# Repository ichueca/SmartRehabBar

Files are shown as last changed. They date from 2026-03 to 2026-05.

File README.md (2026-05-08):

# SmartRehabBar

**SmartRehabBar** es un proyecto centrado en el **desarrollo de un sistema inteligente que se integra en barras de rehabilitación**, permitiendo medir de forma objetiva la fuerza de apoyo ejercida por pacientes durante ejercicios de recuperación funcional.

El sistema utiliza **células de carga** para registrar la carga aplicada, enviando los datos en tiempo real a una plataforma web para su visualización. Esto permite a los profesionales sanitarios realizar un seguimiento cuantitativo de la evolución del paciente.

Además, el proyecto está diseñado con un enfoque **educativo y modular**, facilitando su uso en Formación Profesional y permitiendo futuras ampliaciones como análisis avanzado e integración de inteligencia artificial.

---

## 🎯 Objetivos del proyecto

* Medir de forma objetiva la **fuerza de apoyo** durante ejercicios de rehabilitación.
* Registrar el **tiempo de carga** y detectar descompensaciones.
* Facilitar datos cuantitativos al fisioterapeuta.
* Desarrollar un sistema **replicable, modular y de bajo coste**.
* Servir como base para futuras ampliaciones (doble apoyo, IA, análisis avanzado).

---

## 🧩 Arquitectura general del sistema

El sistema electrónico se compone de los siguientes bloques:

1. Sensórica de fuerza mediante células de carga.
2. Amplificación y conversión ADC con HX711.
3. Microcontrolador ESP32 para procesado y comunicaciones.
4. Sistema de alimentación autónomo con batería Li-Ion.
5. Comunicación WiFi con servidor remoto para visualización de datos.

---

## 🧪 Material electrónico utilizado

### Sensores

* **Células de carga resistivas** (galgas extensométricas).
* Configuración en puente de Wheatstone para mayor estabilidad.

### Conversión y amplificación

* **HX711**

  * ADC de 24 bits específico para células de carga.
  * Alta precisión para señales de baja variación.

### Microcontrolador

* **ESP32 / ESP32-C3 SuperMini**

  * Lectura del HX711.
  * Procesado de datos.
  * Comunicación WiFi.
  * Envío de datos a backend REST.

### Alimentación

* **Batería Li-Ion 18650** (3.0–4.2 V).
* **MCP73871**

  * Gestión de carga.
  * Power-path (uso y carga simultánea).
* **Convertidor Buck-Boost (TPS63020)**

  * Generación de tensión estable para el sistema (3.3 V).
* **Divisor resistivo**

  * Medición del voltaje de batería mediante ADC.

---

## 🧠 Firmware

En este repositorio se incluyen varias versiones del firmware:

### 🔹 PesajeV1

Primera versión funcional del sistema.

**Características:**

* Medición de fuerza en **un único punto de apoyo**.
* Lectura mediante HX711.
* Envío de datos de peso.
* No incluye medición de batería.
* Base para validación inicial.

---

### 🔹 PesajeV2

Versión mejorada del sistema.

**Novedades:**

* ✅ Medición de **nivel de batería en porcentaje**.
* ✅ Lectura de batería mediante ADC + divisor resistivo.
* ✅ Calibración del ADC para mayor precisión.
* ✅ Mejora en estabilidad de lectura.

---

### 🔹 PesajeV3

Versión actual del sistema.

**Novedades principales:**

* ✅ Medición de **doble apoyo (pie izquierdo y derecho)**.
* ✅ Uso de **dos módulos HX711** (uno por cada plataforma).
* ✅ Migración a **ESP32-C3 SuperMini** (reducción de tamaño y consumo).
* ✅ Lectura simultánea de ambos sensores.
* ✅ Envío independiente de datos de cada pie al backend.
* ✅ Mejora en la arquitectura del firmware (estructura modular).

Esta versión permite analizar **asimetrías de carga entre ambos pies**, siendo mucho más útil en entornos reales de rehabilitación.

---

### 🔮 Versiones futuras

* Mejora de filtrado y tratamiento de señal.
* Detección de eventos (apoyo, descarga, equilibrio).
* Optimización de consumo energético.
* Integración de análisis avanzado e IA.
* Visualización avanzada de métricas (balance, evolución, tendencias).

---

## 🔌 Hardware (KiCad)

El repositorio incluye el diseño electrónico completo desarrollado en **KiCad**:

### Contenido:

* 📄 Esquema eléctrico
* 🧩 Diseño de PCB
* 📦 Archivos listos para fabricación

### Versiones:

* Hardware compatible con **PesajeV1**
* Hardware actualizado para **PesajeV2 (medición de batería)**
* 🆕 Hardware **SmartRehab V3**

  * Soporte para **doble HX711**
  * Integración con **ESP32-C3 SuperMini**
  * Optimización del sistema de alimentación
  * Diseño compacto orientado a integración en plataforma

---

## 🔁 Pasos para la replicación

1. Definición del caso de uso.
2. Selección de sensores de fuerza.
3. Integración con HX711.
4. Implementación con ESP32.
5. Diseño del sistema de alimentación.
6. Desarrollo del firmware.
7. Validación con cargas reales.

---

## ⚠️ Consideraciones importantes

* Este sistema es una **herramienta de apoyo**, no un dispositivo médico certificado.
* La fijación mecánica de las células de carga es crítica.
* El sistema está diseñado para ser **modular y ampliable**.
* La medición de batería requiere calibración del ADC.
* Las mediciones de peso requieren **calibración (tara + escala)** tras cambios mecánicos.

---

## 📁 Estructura del repositorio

* `/firmware`

  * `PesajeV1`
  * `PesajeV2`
  * `PesajeV3` 🆕
* `/hardware`

  * `PCB_SmartRehab_V1`
  * `PCB_SmartRehab_V2`
  * `PCB_SmartRehab_V3` 🆕
* `/docs` → Documentación adicional

---

## 📱 Repositorio de la App

Frontend y visualización de datos:
https://github.com/ichueca/SmartRehabBar-App

---

## 👥 Autores

* Jonathan Arizala – https://lasalleberrozpe.eus
* Ainhoa Domínguez – https://nazaret.eus/
* Iñigo Chueca – https://www.zabalburu.org

Proyecto subvencionado por la Viceconsejería de Formación Profesional del Gobierno Vasco a través de https://tknika.eus/

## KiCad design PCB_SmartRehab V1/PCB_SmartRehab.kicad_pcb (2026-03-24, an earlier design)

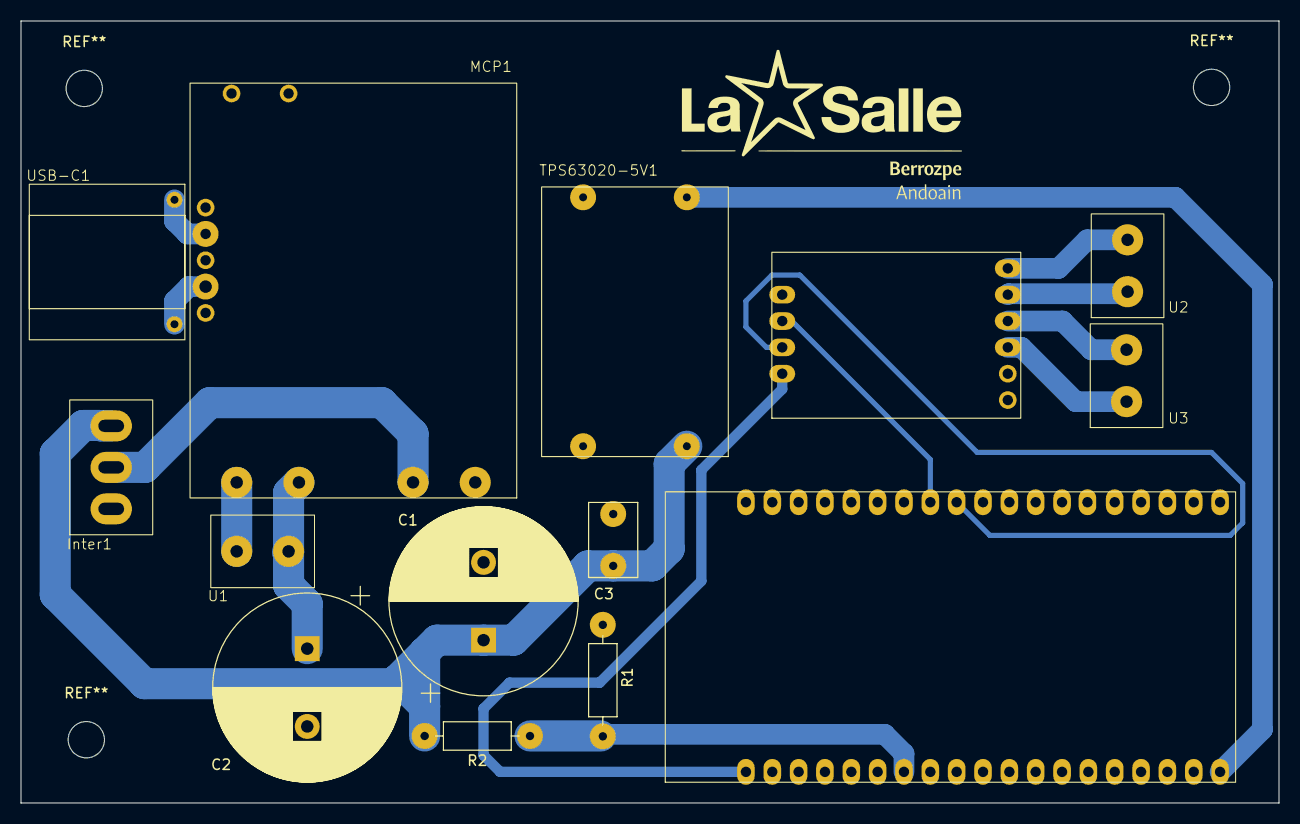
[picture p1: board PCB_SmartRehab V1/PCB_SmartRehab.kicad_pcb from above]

Board: 2 copper layers, 121.3 x 75.4 mm, 14 parts (0 on the bottom side), 16 nets.

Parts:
C1: 4700uF; CP_Radial_D18.0mm_P7.50mm
C2: 1uF; CP_Radial_D18.0mm_P7.50mm
C3: 10uF; C_Rect_L7.0mm_W4.5mm_P5.00mm
ESP32: ESP32
HX711: HX711
Inter1: Interruptor3Pines
MCP1: MCP73871
R1: 10k; R_Axial_DIN0207_L6.3mm_D2.5mm_P10.16mm_Horizontal
R2: 22k; R_Axial_DIN0207_L6.3mm_D2.5mm_P10.16mm_Horizontal
TPS63020-5V1: TPS63020
U1, U2, U3: Conn5mm_02x01
USB-C1: USB-C

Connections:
5V: ESP32.50 (5V), TPS63020-5V1.3 (OUT)
DIV_TENS: ESP32.32 (GPIO32), R1.2, R2.1
GND: C1.2, C2.2, ESP32.40 (GND), HX711.1 (GND), MCP1.4 (GND), R1.1, TPS63020-5V1.2 (GND), TPS63020-5V1.4 (GND)
unnamed: ESP32.55 (3V3), HX711.4 (VCC)
unnamed: ESP32.18 (GPIO18), HX711.3 (SCK)
unnamed: ESP32.19 (GPIO19), HX711.2 (DT)
unnamed: HX711.8 (A+), U3.1
unnamed: HX711.7 (A-), U3.2
unnamed: HX711.5 (E+), U2.2
unnamed: HX711.6 (E-), U2.1
unnamed: MCP1.6 (+), USB-C1.1 (+)
unnamed: MCP1.5 (-), USB-C1.2 (-)
unnamed: C2.1, MCP1.1 (BATT+), U1.1 (BATT+)
unnamed: MCP1.2 (BATT-), U1.2 (BATT-)
unnamed: Inter1.1, MCP1.3 (LOAD)
unnamed: C1.1, C3.1, Inter1.3, R2.2, TPS63020-5V1.1 (VIN)

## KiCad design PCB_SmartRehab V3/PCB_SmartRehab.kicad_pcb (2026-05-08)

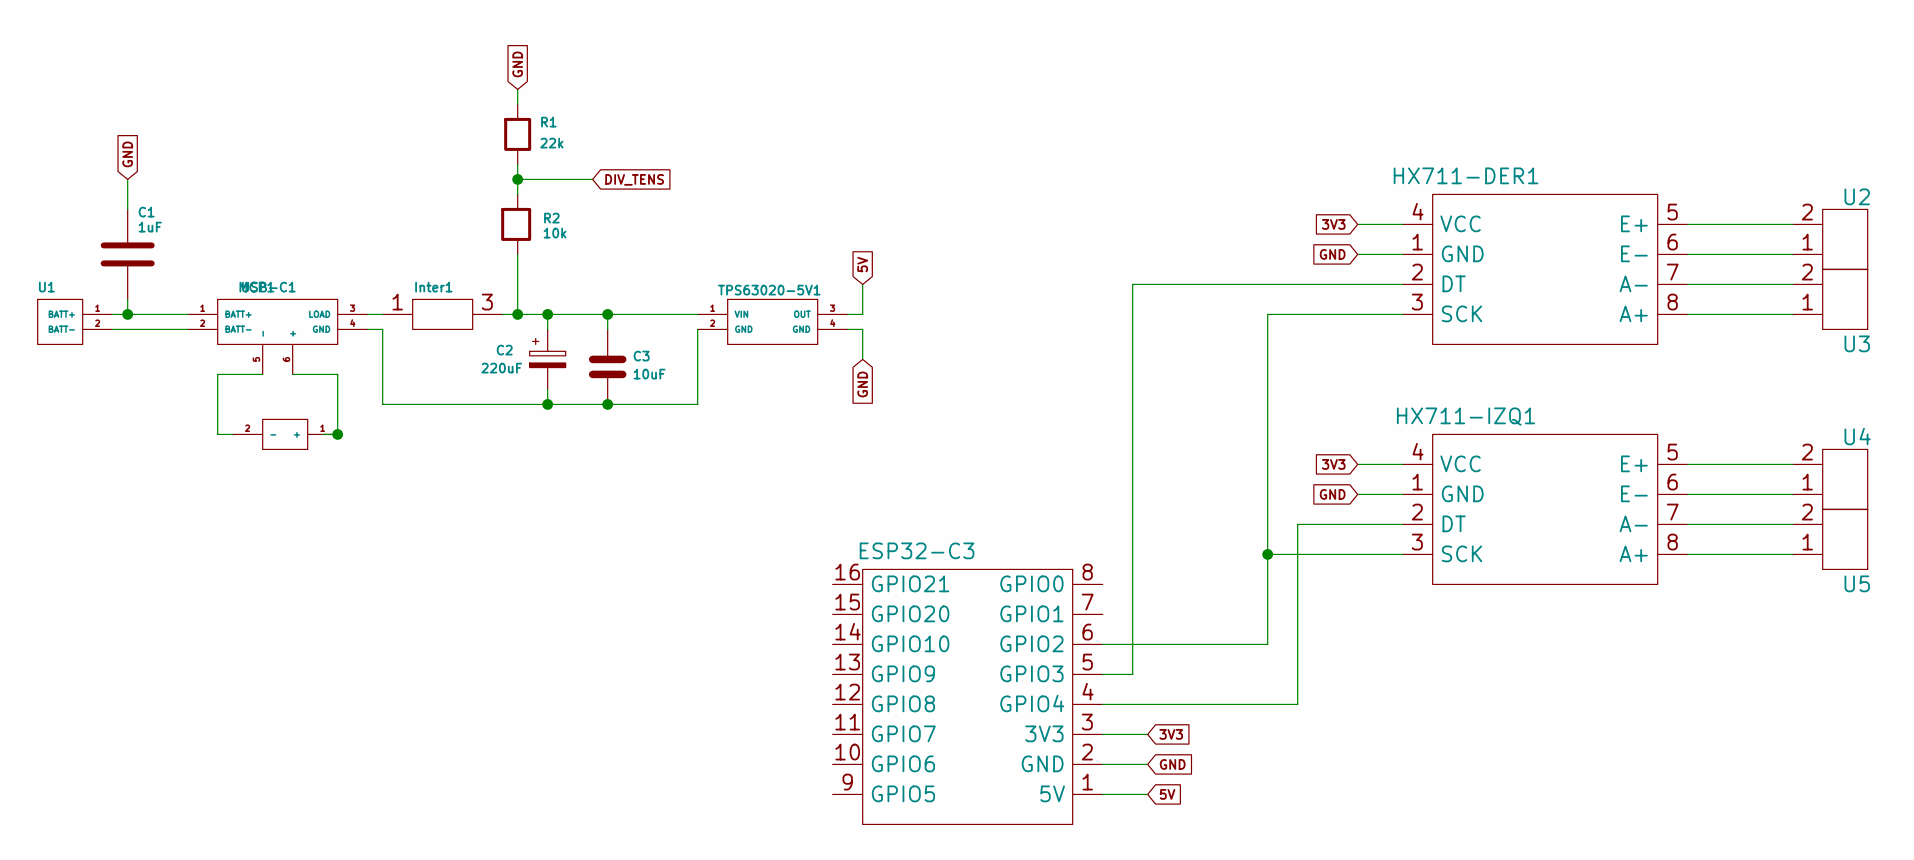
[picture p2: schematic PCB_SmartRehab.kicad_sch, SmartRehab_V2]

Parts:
C1: 1uF; C_Rect_L7.0mm_W6.0mm_P5.00mm
C2: 220uF; CP_Radial_D8.0mm_P3.50mm
C3: 10uF; C_Radial_D5.0mm_H11.0mm_P2.00mm
ESP32-C3: ESP32-C3 Supermini
HX711-DER1, HX711-IZQ1: HX711
Inter1: Interruptor3Pines
MCP1: MCP73871
R1: 22k; R_Axial_DIN0207_L6.3mm_D2.5mm_P10.16mm_Horizontal
R2: 10k; R_Axial_DIN0207_L6.3mm_D2.5mm_P10.16mm_Horizontal
TPS63020-5V1: TPS63020
U1, U2, U3, U4, U5: Conn5mm_02x01
USB-C1: USB-C

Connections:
3V3: ESP32-C3.3 (3V3), HX711-DER1.4 (VCC), HX711-IZQ1.4 (VCC)
5V: ESP32-C3.1 (5V), TPS63020-5V1.3 (OUT)
DIV_TENS: R1.2, R2.1
unnamed: ESP32-C3.6 (GPIO2), HX711-DER1.3 (SCK), HX711-IZQ1.3 (SCK)
unnamed: ESP32-C3.5 (GPIO3), HX711-DER1.2 (DT)
unnamed: ESP32-C3.4 (GPIO4), HX711-IZQ1.2 (DT)
unnamed: HX711-DER1.8 (A+), U3.1
unnamed: HX711-DER1.7 (A-), U3.2
unnamed: HX711-DER1.5 (E+), U2.2
unnamed: HX711-DER1.6 (E-), U2.1
unnamed: HX711-IZQ1.8 (A+), U5.1
unnamed: HX711-IZQ1.7 (A-), U5.2
unnamed: HX711-IZQ1.5 (E+), U4.2
unnamed: HX711-IZQ1.6 (E-), U4.1
unnamed: MCP1.6 (+), USB-C1.1 (+)
unnamed: MCP1.5 (-), USB-C1.2 (-)
unnamed: C1.2, MCP1.1 (BATT+), U1.1 (BATT+)
unnamed: MCP1.2 (BATT-), U1.2 (BATT-)
unnamed: Inter1.1, MCP1.3 (LOAD)
unnamed: C2.1, C3.1, Inter1.3, R2.2, TPS63020-5V1.1 (VIN)

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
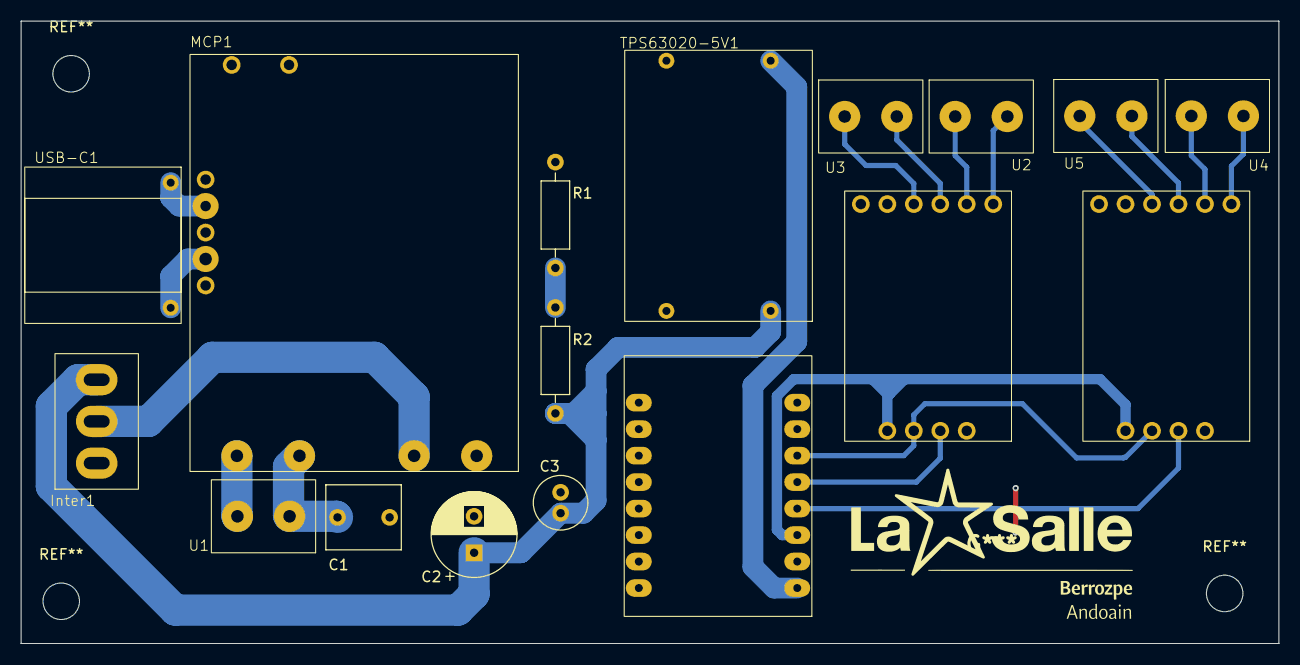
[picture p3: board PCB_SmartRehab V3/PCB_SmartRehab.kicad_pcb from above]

Board: 2 copper layers, 120.7 x 59.7 mm, 17 parts (0 on the bottom side), 21 nets.

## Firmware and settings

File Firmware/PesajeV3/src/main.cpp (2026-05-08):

#include <Arduino.h>
#include <WiFi.h>
#include <HTTPClient.h>
#include "HX711.h"

// --- WIFI ---
const char* ssid     = "IoT";
const char* password = "Gt,N%2$R";

// --- SERVIDOR ---
const char* serverURL = "https://smartrehabbar-demo-7f620514b4ed.herokuapp.com";

// --- HX711 ---
#define DOUT_LEFT   4
#define DOUT_RIGHT  3
#define SCK         2

HX711 scaleLeft;
HX711 scaleRight;

long R0_left = 0;
long R0_right = 0;

double SCALE_left = 25268;
double SCALE_right = 24666;

int SIGN = -1;

// --- BATERÍA ---
#define PIN_BATTERY_ADC 1
const float ADC_REF = 3.3;
const int ADC_MAX = 4095;
const float BAT_DIVIDER = 3.2;

float batteryVoltage = 0;
int batteryPercent = 0;
unsigned long lastBatteryRead = 0;
const unsigned long BATTERY_INTERVAL = 2000;

// --- ENVÍO ---
unsigned long lastSendTime = 0;
const unsigned long SEND_INTERVAL = 150;

float lastWeightLeft = -1;
float lastWeightRight = -1;

const float MIN_WEIGHT_CHANGE = 0.5;

// --- FUNCIONES ---
long readRawAvg(HX711 &scale, int n = 10) {
  return scale.read_average(n);
}

void tareScales() {
  Serial.println("🔧 Tarando...");
  R0_left = readRawAvg(scaleLeft, 30);
  R0_right = readRawAvg(scaleRight, 30);
}

float leerPeso(HX711 &scale, long R0, double SCALE) {
  long r = readRawAvg(scale, 10);
  return SIGN * ((double)(r - R0) / SCALE);
}

void actualizarBateria() {
  int adc = analogRead(PIN_BATTERY_ADC);

  float vOut = (adc / (float)ADC_MAX) * ADC_REF;
  batteryVoltage = vOut * BAT_DIVIDER;

  batteryPercent = constrain(
    100.0 * (batteryVoltage - 3.2) / (4.2 - 3.2),
    0,
    100
  );
}

// --- ENVÍO IZQUIERDO ---
void sendLeft(float weight, int bat) {

  if (lastWeightLeft != -1 && abs(weight - lastWeightLeft) < MIN_WEIGHT_CHANGE) return;

  HTTPClient http;

  String url = String(serverURL) +
               "/api/hardware/left?peso=" + String(weight, 1) +
               "&bat=" + String(bat);

  Serial.println("→ LEFT: " + url);

  http.begin(url);
  int code = http.GET();

  if (code == 200) {
    lastWeightLeft = weight;
  } else {
    Serial.println("❌ LEFT error " + String(code));
  }

  http.end();
}

// --- ENVÍO DERECHO ---
void sendRight(float weight, int bat) {

  if (lastWeightRight != -1 && abs(weight - lastWeightRight) < MIN_WEIGHT_CHANGE) return;

  HTTPClient http;

  String url = String(serverURL) +
               "/api/hardware/right?peso=" + String(weight, 1) +
               "&bat=" + String(bat);

  Serial.println("→ RIGHT: " + url);

  http.begin(url);
  int code = http.GET();

  if (code == 200) {
    lastWeightRight = weight;
  } else {
    Serial.println("❌ RIGHT error " + String(code));
  }

  http.end();
}

// --- SETUP ---
void setup() {
  Serial.begin(115200);
  delay(2000);

  Serial.println("🚀 SmartRehab V4");

  // WiFi
  WiFi.begin(ssid, password);
  Serial.print("Conectando WiFi");

  while (WiFi.status() != WL_CONNECTED) {
    Serial.print(".");
    delay(500);
  }

  Serial.println("\n✅ WiFi conectado");

  // HX711
  scaleLeft.begin(DOUT_LEFT, SCK);
  scaleRight.begin(DOUT_RIGHT, SCK);

  while (!scaleLeft.is_ready() || !scaleRight.is_ready()) {
    Serial.println("⏳ Esperando HX711...");
    delay(500);
  }

  tareScales();

  analogReadResolution(12);
  analogSetPinAttenuation(PIN_BATTERY_ADC, ADC_11db);
}

// --- LOOP ---
void loop() {

  float pesoIzq = leerPeso(scaleLeft, R0_left, SCALE_left);
  float pesoDer = leerPeso(scaleRight, R0_right, SCALE_right);

  if (millis() - lastBatteryRead > BATTERY_INTERVAL) {
    actualizarBateria();
    lastBatteryRead = millis();
  }

  Serial.print("Izq: ");
  Serial.print(pesoIzq, 2);
  Serial.print(" | Der: ");
  Serial.print(pesoDer, 2);
  Serial.print(" | Bat: ");
  Serial.print(batteryPercent);
  Serial.println("%");

  if (pesoIzq > 3.0) {
    sendLeft(pesoIzq, batteryPercent);
  }

  if (pesoDer > 3.0) {
    sendRight(pesoDer, batteryPercent);
  }

  delay(50);
}

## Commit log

2025-12-18 Subida la primera version del programa. Monitorización de 1 balanza en pantalla
2026-03-24 Actualiza README y añade nuevos archivos del proyecto
    Actualiza README y añade nuevos archivos del proyecto
    [PCB_SmartRehab.kicad_pcb, PCB_SmartRehab.kicad_sch]
2026-05-08 Añadida version V3. Ver Readme.
    [PCB_SmartRehab.kicad_pcb, PCB_SmartRehab.kicad_sch]
